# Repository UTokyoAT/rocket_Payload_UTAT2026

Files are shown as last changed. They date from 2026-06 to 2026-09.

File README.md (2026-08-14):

# rocket_Payload_UTAT2026

輸送機班2026年度の新人研修期間中の上級生での活動。CanSatを搭載したペットボトルロケットを開発するためのリポジトリ

---

## ドキュメント

- [環境構築](docs/setup.md)
- [書き込み方法](docs/flashing.md)
- [制御構造・アーキテクチャ](docs/architecture.md)
- [地上局セットアップ](docs/ground-station.md)
- [JLCPCB 発注手順](docs/pcb-ordering.md)

---

## ディレクトリ構造

XIAO ESP32S3を2枚（XIAO1・XIAO2）使い、SPIで接続する構成。詳細は [architecture.md](docs/architecture.md) を参照。

```
rocket_Payload_UTAT2026/
│
├── platformio.ini           # ビルド・ボード・ライブラリ設定（env:xiao1 / env:xiao2 他）
│
├── include/
│   ├── shared.h             # XIAO1タスク間共有データ（SensorData・MissionState）
│   └── spi_protocol.h       # XIAO1⇔XIAO2間のSPIフレーム定義（SpiFrameToXiao2 他）
│
├── src/
│   ├── xiao1/                       # センサー・GPS・誘導PID計算（SPIマスター）
│   │   ├── main.cpp                 # 起動・タスク生成
│   │   └── tasks/
│   │       ├── task_sensor.h        # IMU・気圧・地磁気読み取り＋姿勢フィルタ（100Hz, Core1）
│   │       ├── task_gps.h           # GPS受信・パース（Core0）
│   │       ├── task_navigation.h    # 誘導PID計算（100Hz, Core1）
│   │       ├── task_mission.h       # ミッションステート遷移（20Hz, Core1）
│   │       └── task_spi_link.h      # XIAO2への送信（100Hz, Core1）
│   └── xiao2/                       # モータ駆動・WiFiテレメトリ中継（SPIスレーブ）
│       └── main.cpp
│
├── lib/
│   ├── Sensor/              # BMP280・MPU6050・BMM350 ドライバ＋姿勢フィルタ  ─ XIAO1
│   ├── GPS/                 # TinyGPSPlus ラッパー                          ─ XIAO1
│   ├── PID/                 # 汎用PIDコントローラ                          ─ XIAO1
│   ├── SpiLinkMaster/       # XIAO2へのSPI送信（マスター側）                ─ XIAO1
│   ├── SpiLinkSlave/        # XIAO1からのSPI受信（スレーブ側）              ─ XIAO2
│   ├── Radio/               # WiFi SoftAP・HTTP GETでバイナリフレーム配信（PULL方式） ─ XIAO2
│   ├── Actuator/            # モーター制御（TB6612FNG）                     ─ XIAO2
│   └── Deployer/            # ロケット分離・パラシュート分離（ニクロム線）・LED ─ XIAO1
│
├── ground/
│   ├── receiver.py          # HTTP GETポーリング受信＋CSVロギング＋Tkinter GUI
│   ├── mock_device.py       # 実機なしでreceiver.pyを確認するためのモック
│   ├── requirements.txt
│   └── logs/                # 保存されたCSVログ（.gitignore推奨）
│
├── hardware/
│   ├── kicad/               # KiCad プロジェクトファイル
│   └── jlcpcb/
│       ├── gerbers/         # Gerberファイル（発注用ZIP）
│       ├── bom/             # Bill of Materials
│       └── cpl/             # Component Placement List
│
└── docs/                    # ドキュメント
```

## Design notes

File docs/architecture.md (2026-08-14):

# 制御構造・アーキテクチャ

## 概要

XIAO ESP32S3を **2個** 使用し、SPIで接続する。GPIOがXIAO ESP32S3 1枚では足りない（センサーI2C×3・GPS UART・ニクロム線×2・モーター用SPIをすべて1枚に収められない）ため、役割ごとに基板を分けた。

```
             SPI（XIAO1がマスター）
XIAO1 ─────────────────────────────► XIAO2
（センサー・GNSS・誘導PID）      （モーター駆動・WiFiテレメトリ中継）
```

| | XIAO1（マスター） | XIAO2（スレーブ） |
|---|---|---|
| 役割 | センサー読み取り・GPS・誘導フュージョン・PID計算・ミッションステート管理・ニクロム線分離機構 | モーター駆動・WiFi通信（テレメトリ配信・手動操作受信） |
| 実装方式 | デュアルコア＋FreeRTOSタスク（`loop()`は使わない） | シンプルな`setup()`/`loop()` |
| 主なlib | Sensor, GPS, PID, Deployer, SpiLinkMaster | Radio, Actuator, SpiLinkSlave |
| PlatformIO env | `xiao1` | `xiao2` |

XIAO1が姿勢・GPS・誘導PID出力まで計算しきってSPIでXIAO2へ送り、XIAO2はそれをそのままモータへ反映しつつ、同じフレームをWiFiで地上局へ中継する（地上局からの手動操作コマンドもXIAO2が直接WiFiで受信し、SPI経由の中継はしない）。

SPI通信の詳細（フレームフォーマット・ピン）は末尾の「[XIAO1 ⇔ XIAO2 通信（SPI）](#xiao1--xiao2-通信spi)」を参照。

---

## XIAO1 タスク構成

```
Core 0                            Core 1（リアルタイム系）
────────                          ──────────────────────────────────
taskGPS  priority 3               taskSensor      priority 5  ← 100Hz 最優先
                                   taskNavigation  priority 4  ← 誘導PID計算
                                   taskMission     priority 4  ← ミッションステート遷移
                                   taskSpiLink     priority 3  ← XIAO2への送信
```

Core 1の4タスクはセンサー→誘導PID・ミッション判定→SPI送信の依存順に優先度を割り当てている。

| タスク | 周期 | 役割 |
|---|---|---|
| taskSensor | 100Hz | IMU・気圧・地磁気を読み、姿勢フィルタ（重力ベクトルの相補フィルタ＋地磁気チルト補正）を回す。BMM350のODRも100Hzに設定（`lib/Sensor`） |
| taskNavigation | 100Hz | GPS方位とyawの誤差（磁気偏角補正込み）をPIDで補正し、旋回量(`pidOutput`)と目的地方位(`destinationYaw`)をSharedへ書き込む。GPS fix未取得中は出力0固定 |
| taskMission | 100Hz（10ms） | SETTING〜GOAL/ABORTEDのシーケンスを進行させ`Shared.state`を更新し、`lib/Deployer`（ニクロム線・LED）を制御する。詳細は「[ミッションステート遷移](#ミッションステート遷移)」参照 |
| taskSpiLink | 100Hz | センサー値・誘導PID出力・ミッションステートをXIAO2へ送信し、応答フレーム（地上局が設定した目的地）を受け取る |
| taskGPS | イベント駆動 | NMEAをバイト単位でパース。fix有無・衛星数・新規fix到着を`gpsValid`/`gpsSatellites`/`gpsFixSeq`としてSharedへ書き込む |

---

## タスク間データ共有（XIAO1内）

XIAO1内の全タスクが `Shared` 構造体 1つを参照する。mutex で排他制御。XIAO2とはこの構造体を共有しておらず、taskSpiLinkがSPI経由で値をやり取りする。

```
include/shared.h
┌────────────────────────────────────────────────────┐
│ struct SensorData {                                │
│   float alt, roll, pitch, yaw;                     │
│   double lat, lon;                                 │
│   uint32_t timestamp_ms;                           │
│   bool gpsValid;                                   │
│   int gpsSatellites;      ← taskGPSが計算          │
│   uint32_t gpsFixSeq;     ← taskGPSが計算          │
│   float pidOutput;        ← taskNavigationが計算   │
│   float destinationYaw;   ← taskNavigationが計算   │
│ };                                                  │
│ struct Shared {                                    │
│   SemaphoreHandle_t mutex;                         │
│   SensorData latest;                               │
│   MissionState state;    ← taskMissionが更新       │
│   double goalLat, goalLon; ← taskMission/taskSpiLinkが更新 │
│ };                                                  │
└────────────────────────────────────────────────────┘
```

- **書き込み**: taskSensor（alt/roll/pitch/yaw/timestamp_ms）、taskGPS（lat/lon/gpsValid/gpsSatellites/gpsFixSeq）、taskNavigation（pidOutput/destinationYaw）、taskMission（state/goalLat/goalLon）、taskSpiLink（goalLat/goalLon、地上局が`GET /goal`を送った場合のみ）
- **読み取り**: taskNavigation（yaw/lat/lon/gpsValid/goalLat/goalLon）、taskMission（alt/roll/pitch/gpsValid/gpsSatellites/lat/lon/gpsFixSeq）、taskSpiLink（XIAO2への送信用）

---

## ライブラリ構成（lib/）

タスク／`loop()`はlibの薄いラッパーとして機能し、ロジックはすべてlib側に閉じ込める。

```
src/xiao1/tasks/task_xxx.h                    src/xiao2/main.cpp
    │  lib を呼ぶだけ                              │  lib を呼ぶだけ
    ▼                                              ▼
lib/Sensor/          BMP280（気圧）・MPU6050（6軸）・BMM350（地磁気）ドライバ＋姿勢フィルタ   ─ XIAO1
lib/GPS/             TinyGPSPlus をラップしたGPS読み取りクラス（GY-GPSV2-NEO6M）＋方位・距離計算 ─ XIAO1
lib/PID/             汎用PIDコントローラ                                                  ─ XIAO1
lib/SpiLinkMaster/   XIAO2への送信＋応答受信（全二重SPI、標準SPIライブラリを使用）           ─ XIAO1
lib/SpiLinkSlave/    XIAO1からのトランザクション受信（hideakitai/ESP32SPISlaveを使用）      ─ XIAO2
lib/Radio/           WiFi SoftAP 立ち上げ・HTTP GET でバイナリフレーム配信（PULL方式）        ─ XIAO2
lib/Actuator/        モーター（TB6612FNG、3ピン/モーター＋共有STBY方式で左右独立駆動）         ─ XIAO2
lib/Deployer/        ロケット分離・パラシュート分離（いずれもニクロム線でテグス溶断）・LED     ─ XIAO1
lib/DebugLog/        WiFi SoftAP + HTTPでテキストログ配信（tests/配下の単体動作確認専用。本番では未使用）
```

ミッションステート遷移ロジック自体は`lib/`ではなく`src/xiao1/tasks/task_mission.h`に置いている（Sensor/GPS/Deployerなど複数libを横断的に読み書きする調停役のため、他タスクと同じく「libを呼ぶだけの薄いラッパー」ではなく、libをまたぐ状態管理そのものがこのタスクの本体になる）。

---

## ミッションステート遷移

`src/xiao1/tasks/task_mission.h`（`taskMission`、10ms周期）が実装する。実際の運用フローチャートに基づく7状態。「tick」はtaskMission自身の10ms周期を指す（NAVIGATEの停止判定のみ、GPSの実際の更新間隔に合わせて「新規fixの到着回数」で数える。理由は後述）。tick数（LAUNCH_CONFIRM_TICKS等）は50ms周期だった頃の値のまま据え置いているため、各確認時間は5分の1に短縮されている点に注意。

```
SETTING ──衛星10個以上を捕捉──► LAUNCH ──高度8m超を5tick連続検知──► DETACH
   │ 10分タイムアウト                                                  │ deployRocket()
   ▼                                                                    │ 高度変化1m未満を100tickごとに5回連続検知
ABORTED ◄───────────────────────────────────────────────────────────────┤
   ▲                                                                    ▼
   │ 5分タイムアウト                                                 UNFOLD
   │（安定したが20度以内に収まらない）                                  │ deployParachute()
   └──────────────────────────────────────────────────────────────────┤ 変化幅10度以下(直近10tick)
                                                                        │ かつ絶対値20度以下を5tick連続検知
                                                                        ▼
   ABORTED ◄── 10分タイムアウト（停止を検知できず） ──────────── NAVIGATE
      │                                                                 │ 緯度・経度どちらも変化が0.00001度以下を
      │                                                                 │ 新規fixで1回検知→以後5回連続で再確認
      ▼                                                                 ▼
  LED点滅で異常を通知し続ける                                          GOAL ── LED点滅（回収支援）
  （モータはNAVIGATE以外では動かないため自然に停止する）
```

各遷移のトリガーとしきい値（すべて`task_mission.h`冒頭の定数）：

| 遷移 | トリガー |
|---|---|
| SETTING → LAUNCH | GPS衛星捕捉数が`SETTING_MIN_SATELLITES`（10個）以上、かつfix取得済み。このとき現在のGPS座標を`Shared::goalLat/goalLon`（＝打ち上げ地点）として記録する |
| SETTING → ABORTED | `SETTING_TIMEOUT_MS`（10分）経過しても衛星10個に届かない |
| LAUNCH → DETACH | 高度が`LAUNCH_ALT_THRESHOLD_M`（8m）を`LAUNCH_CONFIRM_TICKS`（5tick=0.05秒）連続で超える。タイムアウトなし（発射操作を待ち続ける） |
| DETACH → UNFOLD | 遷移時に`Deployer::deployRocket()`（ロケットから分離）。以後、`DETACH_ALT_SAMPLE_TICKS`（100tick=1秒）ごとにサンプリングした高度変化が`DETACH_ALT_DELTA_THRESHOLD_M`（1m）未満を`DETACH_CONFIRM_TICKS`（5回連続＝計5秒相当）検知＝着地。タイムアウトなし |
| UNFOLD → NAVIGATE | 遷移時に`Deployer::deployParachute()`（パラシュート分離）。直近`UNFOLD_STABLE_WINDOW_TICKS`（10tick=0.1秒）のroll/pitch変化幅がともに`UNFOLD_STABLE_RANGE_DEG`（10度）以下、かつ`abs(roll)`/`abs(pitch)`がともに`UNFOLD_UPRIGHT_ABS_DEG`（20度）以下を`UNFOLD_UPRIGHT_CONFIRM_TICKS`（5tick=0.05秒）連続で検知 |
| UNFOLD → ABORTED | `UNFOLD_TIMEOUT_MS`（5分）経過しても上記条件を満たさない（変化は収まった＝安定したが20度以内に収まらない＝回収不能と判断） |
| NAVIGATE → GOAL | `Shared::goalLat/goalLon`へ向けた自律走行中、緯度・経度**どちらも**変化が新規GPS fixで`NAVIGATE_STOP_DELTA_DEG`（0.00001度）以下であることを1回でも検知したら「停止候補」とし、そこから改めて新規fix`NAVIGATE_STOP_CONFIRM_FIXES`（5回）分すべてが同条件を満たすことを再確認できたら＝停止（到達）。再確認中に1回でも超えたら候補を取り消し、次に条件を満たす新規fixが来るところから数え直す。片方だけで判定すると、進行方向が南北/東西に近いときもう片方の軸がほぼ動かず誤検知するためAND条件にしている |
| NAVIGATE → ABORTED | `NAVIGATE_TIMEOUT_MS`（10分）経過しても停止を検知できない |

**DETACHの着地判定を1tickではなく100tickごとに間引く理由**：1tick（10ms）間隔の生の高度差分は気圧センサーのノイズで振動しやすく、着地していなくても閾値未満に見えて誤検知しかねない。そのため`DETACH_ALT_SAMPLE_TICKS`（100tick=1秒）間隔で高度をサンプリングして差分を取り、そのサンプル単位で`DETACH_CONFIRM_TICKS`（5回）連続して閾値未満なら着地と判定する（着地判定にかかる時間は合計で約5秒）。

**NAVIGATEの停止判定だけ「tick」ではなく「GPS fix到着回数」で数える理由**：GPSは実際には1Hz程度でしか更新されないため、taskMissionの10ms周期でそのまま緯度経度をサンプリングすると、同じ古い値を何度も連続で読んでしまい「移動していない」と誤判定しかねない。そのため`taskGPS`が新規fix受信のたびインクリメントする`SensorData::gpsFixSeq`の変化を検知したときだけ判定する。

**NAVIGATEの停止判定が「1回検知→改めて5回再確認」の2段構えになっている理由**：最初から5回連続一致を要求すると、たまたま最初の数回だけ条件を満たさなかった場合に0からやり直しになり判定が遅れる。そこで1回でも条件を満たした時点をいったん「停止候補」として記録し、そこから独立に5回分の新規fixで再確認する。再確認の途中で1回でも条件を外れたら停止候補を取り消し、次に条件を満たす新規fixが来たところから改めて5回のカウントを始める。

**ABORTED/GOALの共通挙動**：`Deployer::beepPattern()`を呼び続けてLEDを点滅させ、回収支援の位置知らせを継続する。区別はテレメトリの`mission_state`の値で行う。モータはXIAO2側で`MissionState::NAVIGATE`のときしか自律走行しないため（後述）、ABORTED/GOALでは特別な停止処理をせずとも自然にモータが止まる。

---

## 無線通信

地上PCとはWiFi SoftAPで常時接続し、PULL方式（地上PC側がHTTP GETで定期的に取りに行く）でテレメトリを配信する。SDカードは使用しない。

機体→PCへのPUSH（WebSocketブロードキャストやPOST）は、PC側ファイアウォールに着信をブロックされる環境があり信頼できないため採用しない。地上PCからのアウトバウンドGETは許可されやすいため、PULL方式に統一している。

```
ESP32-S3（SoftAP: CanSat-AP、XIAO2が担当）
    │  GET http://192.168.4.1/data
    │  37バイト バイナリフレーム（ポーリング間隔 100〜150ms 目安）
    ▼
地上PC（ブラウザ or Pythonスクリプト）
    └─ データ記録・リアルタイム表示
```

WiFi/HTTPは**XIAO2**が担当する（XIAO1はSPI送信のみでWiFiを持たない）。XIAO1がSPIで送った`SpiFrameToXiao2`を、XIAO2がXIAO1のloop()内で`Radio::setData()`にそのまま渡し、リクエストごとに読み直して返す（`Radio::poll()` を呼ぶたびに保留中のHTTPリクエストを処理する）。ブラウザ用の簡易ダッシュボード（`GET /`）も同じ `/data` を`fetch()`でポーリングする。

地上局からのモーター手動制御は `GET /motor?left=-255〜255&right=-255〜255` で受け付ける（PCから機体へのアウトバウンド方向なので、`/data`のPULLと同じく信頼できる方向）。`Radio::getMotorCommandLeft()`/`getMotorCommandRight()` は、`MOTOR_COMMAND_TIMEOUT_MS`（1000ms）以上新しいコマンドが来ていなければ自動的に0を返すフェイルセイフを持つ。地上局側（`ground/receiver.py`）は手動制御が有効な間、250ms間隔でコマンドを送り続けることでこのタイムアウトより十分短い周期を維持する。

このコマンドはXIAO2が直接WiFiで受信し、SPI経由の中継はしない（XIAO1はWiFiを持たないため関与しない）。手動操作と自律PID（XIAO1側で計算した`pid_output`）のどちらを優先するかは、`Radio::hasRecentMotorCommand()`（タイムアウト以内に手動コマンドを受信しているか）で`src/xiao2/main.cpp`の`loop()`が判定する。フラグではなく「直近に手動コマンドが来ているか」で判定するため、`SpiFrameToXiao2`側に調停フラグは持たない。ただし自律PID出力（`else if`側）は`mission_state`が`NAVIGATE`のときしか反映されない（手動操作はステートに関わらず常に優先）。詳細は「[ミッションステート遷移](#ミッションステート遷移)」参照。

誘導PIDの目的地座標の既定値は、SETTINGシーケンス完了時に`taskMission`が取得したGPS座標（＝打ち上げ地点）で、以後NAVIGATEはこの地点へ戻る形（return-to-launch）で走行する。地上局はこれを`GET /goal?lat=..&lon=..`でいつでも上書きできる。モーターコマンドと異なりタイムアウトで無効化されない（通信が途切れたからといって目的地を失わせるのは危険なため、明示的に上書きされるまで保持する）。この座標はXIAO1側の誘導計算（`task_navigation.h`）で使うため、XIAO2が受信した値をSPIの応答フレーム（`SpiFrameFromXiao2`、XIAO2→XIAO1方向）に載せてXIAO1へ送り返す。`ground/receiver.py`は`--dest-lat`/`--dest-lon`起動引数を指定すると、地図表示用の目的地としてだけでなくこの`/goal`エンドポイントにも同じ座標を送るため、地上局の表示上の目的地と機体が実際に向かう先が食い違わない。

誘導PIDの統合動作確認は本番のXIAO1+XIAO2ペア（`env:xiao1`/`env:xiao2`をSPI接続）で行うのが基本だが、`tests/test_navigation`はXIAO1単体で誘導ロジックだけを素早く確認するための補助テストとして別途用意している。Sensor・GPSに加え、本来XIAO2側にしかないモーターをベンチ確認用に直結する（`lib/Actuator`はXIAO2の実配線＝I2C/GPSピンと衝突するため使えず、空いているD0-D3で簡易2ピン方式の仮配線にする）。`lib/Radio`を流用し、`GET /goal?lat=..&lon=..`で受け取った目的地へ、GPS fix取得済みの間だけPID走行する（fix未取得・目的地未受信の間はモーターを動かさない）。テレメトリは本番と同じ`SpiFrameToXiao2`レイアウトで`/data`から見られる。

受信バイナリフレームフォーマット（リトルエンディアン、37バイト。`include/spi_protocol.h` の`SpiFrameToXiao2`をそのまま中継しているので詳細はそちら参照）：

| Offset | Size | 型 | フィールド | 備考 |
|---|---|---|---|---|
| 0 | 4 | uint32 | timestamp_ms | 起動からのms |
| 4 | 4 | float32 | alt | 高度 [m] |
| 8 | 4 | float32 | roll | ロール角 [deg] |
| 12 | 4 | float32 | pitch | ピッチ角 [deg] |
| 16 | 4 | float32 | yaw | ヨー角 [deg] |
| 20 | 4 | float32 | lat | 緯度（doubleから縮小） |
| 24 | 4 | float32 | lon | 経度（doubleから縮小） |
| 28 | 1 | uint8 | mission_state | `MissionState`のenum値 |
| 29 | 4 | float32 | pid_output | 誘導PIDの旋回量（-255〜255） |
| 33 | 4 | float32 | destination_yaw | 目的地への方位角 [deg]（磁北基準） |

---

## XIAO1 ⇔ XIAO2 通信（SPI）

XIAO1がマスター、XIAO2がスレーブ。全二重トランザクション1回で双方向のデータを同時にやり取りする。

```
XIAO1（マスター）                              XIAO2（スレーブ）
  taskSpiLink（100Hz）                           loop()
      │  SpiLinkMaster::transfer(out) ──────────►│ SpiLinkSlave::poll(in)
      │  ＝ SPI.transferBytes()（全二重）          │ ＝ ESP32SPISlaveのqueue/trigger方式
      │◄────────────────────────────────────────│ SpiLinkSlave::setResponse(out)
      ▼                                              │
  Shared::goalLat/goalLonを更新                        ├─ モータへ反映（pid_output or 手動コマンド）
  （goal_valid=1のときのみ）                            └─ Radio::setData()でWiFiテレメトリに反映
```

契約は `include/spi_protocol.h` にある。変更する場合は `lib/SpiLinkMaster` と `lib/SpiLinkSlave` 両方への影響を確認すること。

**XIAO1 → XIAO2（`SpiFrameToXiao2`）**

| フィールド | 型 | 備考 |
|---|---|---|
| timestamp_ms | uint32 | 起動からのms |
| alt / roll / pitch / yaw | float32 | XIAO1のSensorでフュージョン済みの姿勢・高度 |
| lat / lon | float32 | GPS座標（doubleから縮小） |
| mission_state | uint8 | `MissionState`のenum値 |
| pid_output | float32 | `task_navigation.h`が計算した誘導PIDの旋回量（-255〜255） |
| destination_yaw | float32 | `task_navigation.h`が計算した目的地への方位角 [deg]（磁北基準） |

XIAO2はこのフレームをそのままWiFiテレメトリとしても中継する（`lib/Radio`参照）。

**XIAO2 → XIAO1（`SpiFrameFromXiao2`）**

| フィールド | 型 | 備考 |
|---|---|---|
| goal_valid | uint8 | 地上局が`GET /goal`を一度でも送っていれば1。0の間は`goal_lat/goal_lon`は不定値でXIAO1側は無視する |
| goal_lat / goal_lon | float32 | 地上局が`GET /goal?lat=..&lon=..`で設定した目的地座標 |

`taskSpiLink`が`goal_valid`を見て、真の場合のみ`Shared::goalLat/goalLon`を上書きする（未設定の間は`shared.h`の既定値のまま）。

### XIAO2側の処理（モータ駆動・WiFi中継）

`src/xiao2/main.cpp` の `loop()` が、受信した`pid_output`を`BASE_SPEED ± pid_output`の左右差動出力に変換する（誘導・PID自体はXIAO1側の`task_navigation.h`で計算済み）。ただしこの自律PID出力は`mission_state`が`MissionState::NAVIGATE`のときしか反映しない（発射・分離・パラシュート展開の最中にモータが勝手に動き出さないための安全ゲート）。`Radio::hasRecentMotorCommand()`が真なら、ミッションステートに関わらず地上局からの手動コマンドを優先する。さらにXIAO1からのSPIフレームが`SPI_LINK_TIMEOUT_MS`（5秒）以上途絶えた場合は、XIAO1側の異常とみなし手動コマンドより優先してモータを強制停止する（`lastSpiFrameMs`で最終受信時刻を追跡）。優先順位は「SPI断 > 手動コマンド > NAVIGATE時の自律PID > それ以外は停止」。現状のTODO：

- `BASE_SPEED`のミッションステート依存化（現状は固定値150）

### SPIピン・ビルド上の注意

- ピン番号は `include/spi_protocol.h` の `SpiPins` 名前空間で定義。SCK/MISO/MOSIはXIAO1・XIAO2共通（D8/D9/D10）だが、CSはXIAO1側`CS_MASTER`（D0）とXIAO2側`CS_SLAVE`（D7）で異なるGPIOに配線されているため分けて定義している。
- XIAO2は `hideakitai/ESP32SPISlave` ライブラリに依存する（`platformio.ini` の `env:xiao2` にのみ追加）。マスター用（`lib/SpiLinkMaster`）とスレーブ用（`lib/SpiLinkSlave`）を別々のlibフォルダに分けているのは、PlatformIOのライブラリ依存解決がフォルダ単位でソースをコンパイルするため、同じフォルダに同居させるとXIAO1のビルドにもXIAO2専用ライブラリへの依存が混入してしまうことを避けるため。

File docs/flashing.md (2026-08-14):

# 書き込み方法

機体には XIAO ESP32S3 が **2枚** 搭載されている（[architecture.md](architecture.md) 参照）。それぞれ別のファームウェアなので、両方とも個別に書き込む必要がある。

| 基板 | 役割 | PlatformIO env |
|---|---|---|
| XIAO1 | センサー・GPS・誘導PID計算（SPIマスター） | `xiao1` |
| XIAO2 | モータ駆動・WiFiテレメトリ中継（SPIスレーブ） | `xiao2` |

---

## 1. ボードをPCに接続

USB-Cケーブルで **書き込みたい方の** XIAO ESP32S3 を接続する（2枚同時にPCへ挿してもよいが、書き込み対象を間違えないようCOMポートを確認すること）。

デバイスマネージャー（またはターミナル）でCOMポートが認識されているか確認する。

```powershell
# Windows PowerShell で確認
[System.IO.Ports.SerialPort]::GetPortNames()
```

---

## 2. ビルドして書き込む

**VS Code の PlatformIO サイドバー（アリのアイコン）から操作する：**

```
PlatformIO サイドバー → PROJECT TASKS → xiao1（またはxiao2）
  ├─ Build       ← コンパイルのみ
  ├─ Upload      ← ビルド＋書き込み
  └─ Monitor     ← シリアルモニタ（115200 baud）
```

XIAO1用のファームウェアを書き込むときは `xiao1`、XIAO2用（モーター側）を書き込むときは `xiao2` を選ぶこと。VS Code右下のステータスバーで現在選択中の環境が確認できる。

**ショートカット（現在選択中の環境に対して実行される）：**

| 操作 | ショートカット |
|---|---|
| ビルド | `Ctrl+Alt+B` |
| 書き込み | `Ctrl+Alt+U` |
| シリアルモニタ | `Ctrl+Alt+S` |

XIAO2の初回ビルド時は `hideakitai/ESP32SPISlave` ライブラリが自動でダウンロードされる（ネット接続が必要）。

---

## 3. 書き込みに失敗する場合

XIAO ESP32S3 はネイティブUSBの自動リセットで通常は書き込みモードに入るが、失敗する場合は基板上の **BOOTボタン（Bと刻印）を押しながらUSBケーブルを挿す**（またはUploadを開始してから数秒BOOTを押し続ける）と強制的に書き込みモードになる。

```
Upload開始のログが出た直後に BOOTボタンを押す → 離す
```

`platformio.ini` の該当envでポートを固定したい場合：

```ini
[env:xiao1]
extends = common
build_src_filter = -<*> +<../src/xiao1/>
upload_port = COM3   ; 自分の環境のCOMポートに変更
monitor_port = COM3
```

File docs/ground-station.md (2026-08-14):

# 地上局セットアップ

## 構成

テレメトリはPULL方式: 地上PC側（ブラウザ／Pythonスクリプト）が機体の `GET /data` を定期的にポーリングしにいく。機体からPCへ能動的にデータを送りつけることはしない（PC側ファイアウォールに阻まれ信頼できないため）。

モーター手動制御はその逆方向（PC→機体のアウトバウンド `GET /motor?left=N&right=M`）で、こちらは`/data`のPULLと同じくPC側から能動的に接続するので信頼できる。左右独立に指定し、機体側は1秒間コマンドを受信しないと自動的に両方の出力を0にするフェイルセイフを持つ。ただし自律PID走行はミッションステートが`NAVIGATE`のときしか反映されない（`src/xiao2/main.cpp`参照）ため、手動操作もその他の状態では実質的にモータを直接動かすだけになる。

誘導PIDの目的地座標も同じ方向（`GET /goal?lat=..&lon=..`）で設定できる。モーターコマンドと異なりタイムアウトでは無効化されず、明示的に上書きされるまで保持される。既定ではSETTINGシーケンス完了時に機体が取得したGPS座標（打ち上げ地点）が目的地になるが、`/goal`を送ればいつでも優先的に上書きできる。

```
ESP32-S3（CanSat）                  地上PC
──────────────────                 ─────────────────────────────────────
WiFi SoftAP                        1. CanSat-AP に接続
  SSID: CanSat-AP   ←── 接続 ──
  IP:   192.168.4.1

GET /       ──── HTML ──────────► 2. ブラウザで 192.168.4.1 を開く
GET /data   ──── 37byte frame ──► 3. ダッシュボードが150ms間隔でポーリング表示
GET /data   ──── 37byte frame ──► 4. receiver.py が100〜150ms間隔でポーリングし CSV に保存
GET /motor?left=N&right=M ◄── ok ─ 5. receiver.py の左右手動制御スライダーが250ms間隔で送信
GET /goal?lat=..&lon=..   ◄── ok ─ 6. receiver.py が --dest-lat/--dest-lon 指定時に起動時1回送信
```

---

## 単体動作確認テスト（tests/）のデバッグ出力

`tests/` 配下の各動作確認コード（`test_bmm350`・`test_bmp280`・`test_gps`・`test_i2c_scan`・`test_motor`・`test_mpu6050`）は、USBシリアルではなく **WiFi経由** でログを出す（`lib/DebugLog`）。卓上でUSBケーブルを挿さなくても、PCやスマホから確認できる。

1. PCのWiFiを **CanSat-AP** に接続（パスワード: `cansat2026`）
2. ブラウザで `http://192.168.4.1` を開く（300ms間隔で自動更新される簡易ログビューア）
   - または `GET http://192.168.4.1/log` をポーリングすればプレーンテキストで直近60行が取れる（`curl`や自作スクリプトから見る場合はこちら）

本番ファームウェア（XIAO2の`lib/Radio`）と同じSSID/パスワードを使っているため、複数の基板・テストを同時にAPとして起動しないこと（同じSSIDが衝突する。1枚ずつ書き込んで確認する運用を前提にしている）。

`Serial.begin(115200)`自体は残しているため、USBシリアルを接続していれば`DebugLog::printf()`の内容はそちらにも同時出力される（WiFiが使えない環境でのフォールバック）。

---

## test_navigation（XIAO1単体の誘導PID確認）

`tests/test_navigation`はXIAO1単体で誘導ロジックだけを素早く確認するためのテスト（`lib/DebugLog`ではなく`lib/Radio`を流用しており、本番の`/data`と同じフレームで見える）。

1. PCのWiFiを **CanSat-AP** に接続（パスワード: `cansat2026`）
2. `GET http://192.168.4.1/goal?lat=..&lon=..` で目的地を送る（ブラウザのアドレスバーでも`curl`でもよい）
3. ブラウザで `http://192.168.4.1` を開くか`receiver.py --host 192.168.4.1`で`pid_output`・`destination_yaw`・`yaw`・GPS座標を確認する

GPS fixを取得できていない、または目的地を一度も送っていない間はモーターが動かない（`pid_output`は0のまま）。動作確認するモーターは本番のXIAO2用配線ではなく、このテスト専用にD0-D3へ仮配線する（`tests/test_navigation/main.cpp`冒頭のコメント参照）。まずは車輪を浮かせた状態で確認すること。

---

## ブラウザダッシュボード

追加ソフト不要。ESP32-S3 から HTML を配信するため、接続後にブラウザで開くだけで使える。

1. PCの WiFi を **CanSat-AP** に接続（パスワード: `cansat2026`）
2. ブラウザで `http://192.168.4.1` を開く

表示内容：
- ミッションステート
- 高度・姿勢（Roll / Pitch / Yaw）
- GPS座標
- 誘導PID出力・目的地方位
- 高度の時系列グラフ（直近300点）

ページは`/data`を150ms間隔でGETポーリングしており、取得に失敗すると状態表示が「● unreachable」になる（自動的にポーリングを継続し、次に成功すれば「● reachable」に戻る）。目的地までの距離・方位・地図表示・モーター手動制御はブラウザ版では提供していない（Pythonレシーバー側のみ）。

---

## Python レシーバー（CSV ロギング＋GUI）

### セットアップ

```bash
cd ground
pip install -r requirements.txt   # GUIの地図描画に matplotlib を使用
```

GUI表示には Tkinter（python.org配布のWindows版インストーラに標準同梱）と matplotlib を使用する。

### 実行

```bash
python receiver.py
```

- Tkinterウィンドウが開き、以下をリアルタイム表示する：
  - ミッションステート・高度・姿勢（Roll/Pitch/Yaw）・GPS座標
  - 誘導PID出力（数値＋バーゲージ、-255〜255）・目的地方位（磁北基準）
  - 高度の時系列チャート
  - 現在地・機体の向き（矢印）・移動軌跡・東西南北を表示するマップ（matplotlib）
  - 目的地までの距離・方位（`--dest-lat`/`--dest-lon` 指定時のみ）
  - 左右独立の手動モーター制御パネル（下記参照）
- `ground/logs/log_YYYYMMDD_HHMMSS.csv` に自動保存
- ターミナルにも1行readoutを表示する
- GET取得に失敗しても落ちずに警告を出しながらポーリングを継続する
- ウィンドウを閉じる、または `Ctrl+C` で停止

#### 手動モーター制御（左右独立）

「有効にする」チェックボックスをオンにすると、LEFT/RIGHT各スライダー（-255〜255）の現在値を `GET /motor?left=N&right=M` として250ms間隔で機体に送り続ける。チェックを外す・STOPボタンを押す・ウィンドウを閉じる、のいずれでも即座に両方0を送信する。

安全機構（多重化）：
1. チェックを外す/STOP/終了時に明示的に left=0, right=0 を送信
2. チェックを外すと両スライダーは無効化され、それ以上コマンドを送らなくなる
3. 機体側（`Radio::getMotorCommandLeft()`/`getMotorCommandRight()`）は1秒間新しいコマンドを受信しないと自動的に両方の出力を0にする（WiFi切断や地上局クラッシュ時のフェイルセイフ）

チェックを入れた直後は実際にモーターが動くので、卓上テスト時はモーターへの配線状態に注意すること。

目的地を指定すると、マップ上に目的地（★マーク）が表示され、現在地からの距離・方位も表示される：

```bash
python receiver.py --dest-lat 35.6820 --dest-lon 139.7670
```

目的地を指定しない場合、マップは最初に受信した位置を原点として機体の軌跡・向きのみを表示する（東西南北の向きは変わらない）。

Tkinter/matplotlibが使えない環境向けに、GUIなしのターミナル＋CSVのみのモードもある（手動モーター制御はGUI専用のためheadlessでは使えない）：

```bash
python receiver.py --headless
```

接続先IPやポーリング間隔を変えたい場合：

```bash
python receiver.py --host 192.168.4.1 --interval-ms 150
```

### CSV フォーマット

| 列 | 内容 | 単位 |
|---|---|---|
| timestamp_ms | ESP32-S3 起動からの経過時間 | ms |
| alt_m | 高度 | m |
| roll_deg | ロール角 | deg |
| pitch_deg | ピッチ角 | deg |
| yaw_deg | ヨー角 | deg |
| lat | 緯度 | deg |
| lon | 経度 | deg |
| state | ミッションステート名 | - |
| pid_output | 誘導PIDの旋回量 | -255〜255 |
| destination_yaw_deg | 目的地への方位角（機体側計算、磁北基準） | deg |
| dist_to_dest_m | 目的地までの距離（`--dest-lat`/`--dest-lon`未指定時は空欄） | m |
| bearing_to_dest_deg | 目的地への方位（同上、未指定時は空欄） | deg |

### ターミナル表示例

```
Polling http://192.168.4.1:80/data every 120ms ...
Destination: 35.682000, 139.767000
Logging to logs/log_20260101_120000.csv

[NAVIGATE    ] alt= 120.30m  R=  -3.1°  P=   1.8°  Y= 275.0°  GPS=35.68124,139.76713  PID=   0.0  DESTYAW=  34.2°  DIST=  102.4m BRG= 34.2°
```

### 実機なしでの動作確認（モックデバイス）

実機が手元になくても、`mock_device.py` を使って `receiver.py` の動作を確認できる。

```bash
# ターミナル1
python mock_device.py

# ターミナル2
python receiver.py --host 127.0.0.1 --port 8000 --dest-lat 35.6820 --dest-lon 139.7670
```

`mock_device.py` は正弦波で変化するダミーの37バイトフレームを `http://127.0.0.1:8000/data` に配信し続ける。`GET /motor?left=N&right=M` も受け付け、機体と同じ1秒フェイルセイフ付きで`pid_output`（left側の値）に折り返すため、GUIの左右スライダーを動かして手動制御パネルの動作を実機なしで確認できる。`GET /goal?lat=..&lon=..` も200 okを返すだけの受け口として用意してあり、`--dest-lat`/`--dest-lon`指定時に`receiver.py`が自動送信する`GoalSender`が無限リトライし続けないようにしている。

---

## バイナリフレームフォーマット（参考）

ESP32-S3（XIAO2）が `/data` で配信する37バイトのバイナリフレーム（リトルエンディアン）。XIAO1がSPIで送った`SpiFrameToXiao2`（`include/spi_protocol.h`）をXIAO2がそのまま中継したもので、`lib/Radio/Radio.h`・`ground/receiver.py`・`lib/Radio/dashboard.h` の3箇所で共有する契約。Python側フォーマット文字列は `"<IffffffBff"`。

| Offset | Size | 型 | フィールド | 備考 |
|---|---|---|---|---|
| 0 | 4 | uint32 | timestamp_ms | 起動からのms |
| 4 | 4 | float32 | alt | 高度 [m] |
| 8 | 4 | float32 | roll | ロール角 [deg] |
| 12 | 4 | float32 | pitch | ピッチ角 [deg] |
| 16 | 4 | float32 | yaw | ヨー角 [deg] |
| 20 | 4 | float32 | lat | 緯度（機体側でdoubleから縮小） |
| 24 | 4 | float32 | lon | 経度（機体側でdoubleから縮小） |
| 28 | 1 | uint8 | mission_state | 下表参照 |
| 29 | 4 | float32 | pid_output | 誘導PIDの旋回量（-255〜255）。地上局の手動制御（`GET /motor`）が有効な間はXIAO2がそちらを優先してモータへ反映する |
| 33 | 4 | float32 | destination_yaw | 目的地への方位角 [deg]（磁北基準、XIAO1が計算） |

`mission_state` の値と対応するステート（詳細は `docs/architecture.md` の「ミッションステート遷移」参照）：

| 値 | ステート |
|---|---|
| 0 | SETTING |
| 1 | LAUNCH |
| 2 | DETACH |
| 3 | UNFOLD |
| 4 | NAVIGATE |
| 5 | GOAL |
| 6 | ABORTED |

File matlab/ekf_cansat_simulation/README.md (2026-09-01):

# CanSat 2輪走行EKF MATLABシミュレーション

`EKF_MATLAB_simulation_requirements.md`（状態遷移・観測モデル・EKF予測/更新の数式）を
土台に、出発点から約50m先の目的地へ向かう目的地誘導シナリオを実装したもの。
`run_goal_directed_simulation.m` を実行すると、Phase0（静止）→ キャリブレーション走行
（直進のみでGNSS変位から初期方位角を推定）でEKFを初期化した後、方向転換のたびに
**その時点のEKF推定位置**（実機が実際に使える唯一の情報。真値は使わない）から見た
目的地への方位角を計算して機体を向け直し、1レグ分直進する、という誘導を目的地到達
まで繰り返す。EKFの推定誤差が誘導そのものに影響する閉ループシミュレーション。
外部Toolbox不使用（`randn`/`rng`/`polyfit`等コア関数のみ）。

## ファイル構成

| ファイル | 役割 |
|---|---|
| `config_params_goal.m` | `config_params.m` を継承し、目的地・誘導ロジックのパラメータを追加 |
| `config_params.m` | 基本パラメータを一元管理（センサノイズ・機体寸法・周期など） |
| `simulate_segment.m` | 任意の初期状態から、与えた制御入力列に沿って真値・観測値を1ステップずつ生成（実行時に長さが決まる区間を継ぎ足すため） |
| `simulate_goal_directed.m` | シナリオ本体（Phase0初期化→目的地誘導ループ）。`use_encoder`フラグでEKFのエンコーダ更新有無を切り替え可能 |
| `run_ekf_over_range.m` | EKFループ本体（予測→[エンコーダ更新]→GNSS更新）を、任意区間に対して呼べる関数にしたもの。`use_encoder=false`でエンコーダ更新を丸ごとスキップ |
| `encoder_counts_to_velocity.m` | AS5600生カウント差分→ホイール周速（ラップアラウンド処理込み） |
| `latlon_to_local.m` / `local_to_latlon.m` | 緯度経度⇔ローカル座標変換 |
| `ekf_predict.m` | EKF予測ステップ |
| `ekf_update.m` | EKF更新ステップ（エンコーダ・GNSS共通の汎用形） |
| `run_goal_directed_simulation.m` | メインスクリプト（標準版、エンコーダ+GNSS） |
| `run_goal_directed_simulation_no_encoder.m` | メインスクリプト（比較版、GNSSのみ・エンコーダ更新なし） |
| `plot_results_goal.m` | 検証プロット（軌道比較の全区間図＋先頭Nレグ切り抜き図、状態誤差と±3σ） |

**誘導ロジック**: 方向転換のたびに、EKF推定位置から見た目的地への方位角を計算し、
その方向へ機体を向けてから1レグ（`leg_duration_s`秒、時間ベース）だけ直進する。目的地到達判定
（`arrival_tolerance_m`以内）もEKF推定位置基準。

**エンコーダなし比較**: `run_goal_directed_simulation_no_encoder.m` は同じシナリオ・同じ
乱数シードのまま、EKFのエンコーダ更新ステップだけを無効化する（予測+GNSS 1Hz更新のみ）。
`run_goal_directed_simulation.m` と見比べることで、車輪エンコーダによる速度フィルタリング
の有無が推定精度・誘導の安定性にどれだけ効いているかを比較できる。

**先頭Nレグの切り抜きマップ**: `plot_results_goal.m` は全区間の軌道図に加えて、
`N_LEGS_CROP`（デフォルト5）で指定した先頭レグ分だけに絞った軌道図も表示する
（走り始めの挙動を拡大して見るため、ゴール・到達許容円はこの図には出さない）。

## 実装時に補った設計判断

- **真のIMUバイアス `b_a_true`, `b_g_true`**: EKF側の過程ノイズ `sigma_rw_a`, `sigma_rw_g`
  と同じスケールでランダムウォークさせている（`simulate_segment.m`）。EKFのバイアス
  追従性能を検証する目的。固定値にしたい場合は `config_params.m` の該当sigmaを
  実質0にすればよい。
- **GNSS疑似観測値**: 真の位置→緯度経度（センサ理想出力）→位置ドメインで正規分布
  ノイズを緯度経度に変換して付加→生の緯度経度、という往復を実装。
- **エンコーダのラップアラウンド**: AS5600の12bitレジスタ差分を[-2048,2048)カウントに
  正規化してから角度差に変換。1ステップ(dt=0.05s)内に半回転を超える場合は正しく
  デラップできない前提（デフォルトパラメータでは十分な余裕あり）。
- **方向転換フェーズの走行速度**: 「左右輪駆動を想定した一定角速度」との記述から、
  その場旋回（並進速度v=0でθのみ変化）と解釈した。
- **直進の加減速モデル**: 実機は速度切替がほぼ瞬時と想定し、最初と最後の1ステップ
  (=dt=0.05s)だけ加減速するbang-bangモデル（`simulate_segment.m`内で `v_cruise/dt` の
  スパイクとして実装）。
- **旋回角**: 固定角ではなく、「EKF推定位置から見た目的地方位 − EKF推定方位角」で
  必要な旋回角を都度算出する。旋回自体はオープンループ（算出した角度÷目標角速度の
  時間だけ回頭）で、旋回中に姿勢をフィードバック補正するモデルにはしていない。
- **真の初期方位角(`theta_true_init_deg`)**: 電源投入時に機体が実際にどちらを向いて
  いるかは、静止しているPhase0中のGNSSだけではわからない（COGは移動していないと
  出ない）ため、真値側は意図的にEKFの初期の当て推量とは異なる値（デフォルト130°）に
  してある。方位角が本当に未知であることをテストするための仕掛けであり、実測すべき
  ハードウェアパラメータではない。
- **初期方位角のキャリブレーション走行**（`simulate_goal_directed.m`のPhase0直後）:
  旋回コマンドは「目的地方位 − EKF推定方位角」という*相対*角度で計算されるため、
  θの初期推定が大きく外れているとその誤差が旋回結果にそのまま乗ってしまい、GNSS
  補正だけでは収束が遅い/安定しないことがある。そこでPhase0の後、`T_calib_straight`
  秒（デフォルト10秒＝1レグと同じ長さ）だけ旋回せずに直進し、得られた複数のGNSS fix
  を時刻に対して1次回帰（`polyfit`）した傾きからEKFの初期方位角`theta_cal`とその
  推定誤差`sigma_theta_cal`を求め、それぞれx0(4)とP0(4,4)に使う。ただし`v_cruise`が
  遅くGNSSノイズが大きい設定だと、10秒の走行距離（例: 0.3m/s×10s=3m）がGNSSノイズ
  標準偏差（例: 2.12m）と同程度になり、較正の効きが弱くなる（推定誤差が1σ=40〜50°
  程度残ることもある）。実行時にコンソールへ推定値・真値との誤差・1σを表示するので、
  改善したい場合は`T_calib_straight`を伸ばすか`v_cruise`を上げると効果が大きい
  （不確かさは走行距離のほぼ逆数的に縮む）。

## 後日実測値に差し替えるべきパラメータ

`config_params.m` 内の「後日実測値に差し替え」コメント箇所（`r`, `L`,
`sigma_theta_R/L`, `sigma_a`, `sigma_rw_a`, `sigma_g`, `sigma_rw_g`, `sigma_N`, `sigma_E`,
`P0_diag`）と `config_params_goal.m` の目的地・誘導パラメータが対象。

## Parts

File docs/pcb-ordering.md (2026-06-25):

# JLCPCB 発注手順

## 必要なファイル

| ファイル | 説明 | 出力元 |
|---|---|---|
| Gerber（ZIP） | 基板データ本体 | KiCad → Plot |
| BOM（CSV） | 部品リスト（LCSC部品番号付き） | KiCad → BOM Plugin |
| CPL（CSV） | 部品実装座標リスト | KiCad → Fabrication Outputs |

出力ファイルは `hardware/jlcpcb/` に格納する。

---

## KiCad からのファイル出力手順

### Gerber

1. PCBエディタ → `File` → `Fabrication Outputs` → `Gerbers (.gbr)`
2. 出力先を `hardware/jlcpcb/gerbers/` に設定
3. 以下のレイヤーにチェックを入れる：
   - F.Cu / B.Cu（銅箔）
   - F.Silkscreen / B.Silkscreen（シルク）
   - F.Mask / B.Mask（ソルダーマスク）
   - Edge.Cuts（外形）
4. `Plot` → 続けて `Generate Drill Files`
5. `gerbers/` フォルダをZIPに圧縮してアップロード

### BOM（PCBA発注時のみ）

1. PCBエディタ → `File` → `Fabrication Outputs` → `BOM`
2. LCSC部品番号は部品プロパティの `LCSC` フィールドに記入しておく
3. 出力を `hardware/jlcpcb/bom/bom.csv` に保存

### CPL（PCBA発注時のみ）

1. PCBエディタ → `File` → `Fabrication Outputs` → `Component Placement (.pos)`
2. 形式: CSV、単位: mm、個別ファイル（表面・裏面）
3. 出力を `hardware/jlcpcb/cpl/` に保存

---

## JLCPCB サイトでの発注

1. [jlcpcb.com](https://jlcpcb.com/) にアクセス
2. `Order Now` → Gerber ZIPをアップロード
3. 基板仕様を設定（枚数・板厚・色など）
4. PCBA（実装）が必要な場合は `PCB Assembly` をONにしてBOM・CPLをアップロード
5. BOM確認画面でLCSC部品番号を照合して発注

---

## フォルダ構成

```
hardware/jlcpcb/
├── gerbers/    # Gerberファイル（ZIP化してアップロード）
├── bom/        # Bill of Materials（部品リスト）
└── cpl/        # Component Placement List（実装座標）
```

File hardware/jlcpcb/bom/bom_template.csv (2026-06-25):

Comment | Designator | Footprint | LCSC
100nF 10V | C1 | C_0402 | C1525
10kΩ | R1 | R_0402 | C25744

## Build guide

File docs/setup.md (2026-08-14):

# 環境構築

## 使用マイコン

**Seeed Studio XIAO ESP32S3**（ESP32-S3、8MB Flash / 8MB PSRAM）を **2枚** 使用し、SPIで接続する（GPIO数の都合上、センサー・GPS・誘導PID計算担当のXIAO1と、モータ駆動・WiFiテレメトリ担当のXIAO2に役割を分けている）。詳細は [architecture.md](architecture.md) を参照。

---

## 1. 必要なソフトウェアのインストール

| ソフトウェア | 説明 |
|---|---|
| [VS Code](https://code.visualstudio.com/) | エディタ |
| [PlatformIO IDE（VS Code拡張）](https://platformio.org/install/ide?install=vscode) | ESP32への書き込み・ビルド環境 |

> PlatformIO IDE をインストールすると、必要なコンパイラ・ツールチェーンが自動でインストールされます。

---

## 2. USBドライバのインストール（Windows）

XIAO ESP32S3 は ESP32-S3 のネイティブUSB（USB CDC）でPCと直接通信するため、CP2102 / CH340 のような外付けドライバは**不要**。USB-Cケーブルで接続すればデバイスマネージャーの「ポート」欄にCOMポートとして認識される。

---

## 3. リポジトリのクローン

```bash
git clone <このリポジトリのURL>
cd rocket_Payload_UTAT2026
```

---

## 4. VS Code でプロジェクトを開く

```
VS Code → File → Open Folder → rocket_Payload_UTAT2026 フォルダを選択
```

PlatformIO が `platformio.ini` を検出し、自動でライブラリ・依存関係をダウンロードする。

---

## 5. 書き込み方法

詳細は [flashing.md](flashing.md) を参照。

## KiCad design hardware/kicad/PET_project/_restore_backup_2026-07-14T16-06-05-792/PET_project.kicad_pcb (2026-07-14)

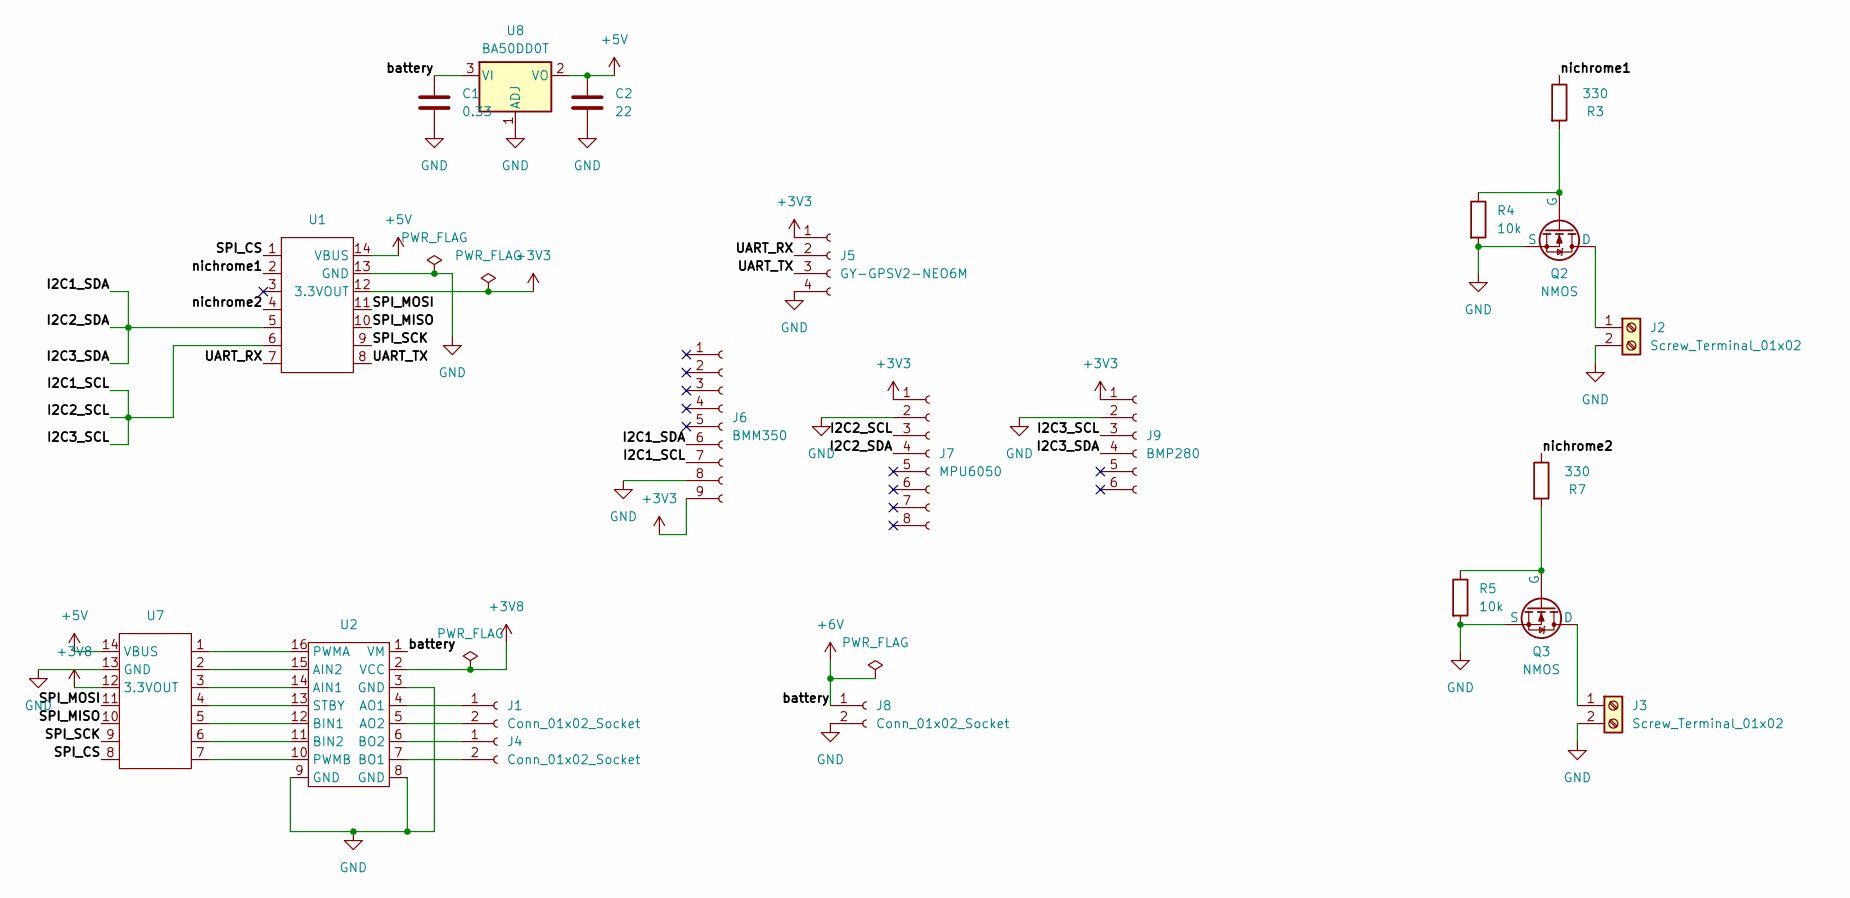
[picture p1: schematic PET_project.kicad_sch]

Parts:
C1: 0.33; CP_Radial_Tantal_D4.5mm_P5.00mm
C2: 22; C_Radial_D5.0mm_H11.0mm_P2.00mm
J1, J4: Conn_01x02_Socket; JST_XH_S2B-XH-A_1x02_P2.50mm_Horizontal
J2, J3: Screw_Terminal_01x02; TerminalBlock_Phoenix_MKDS-1,5-2-5.08_1x02_P5.08mm_Horizont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
J5: GY-GPSV2-NEO6M
J6: BMM350; BMM350_PinSocket_Vertical
J7: MPU6050; MPU6050_PinSocket_Vertical
J8: Conn_01x02_Socket; JST_PH_S2B-PH-K_1x02_P2.00mm_Horizontal
J9: BMP280; BMP280_PinSocket_Vertical
Q2, Q3: NMOS; TO-220-3_Vertical
R3, R7: 330; R_Axial_DIN0204_L3.6mm_D1.6mm_P2.54mm_Vertical
R4, R5: 10k; R_Axial_DIN0204_L3.6mm_D1.6mm_P2.54mm_Vertical
U1, U7: XIAO-ESP32-S3-DIP
U2: TB6612FNG
U8: BA50DD0T; TO-220-3_Vertical

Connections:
+3V3: J5.1, J6.9, J7.1, J9.1, U1.12 (3.3VOUT)
+3V8: U2.2 (VCC), U7.12 (3.3VOUT)
+5V: C2.1, U1.14 (VBUS), U7.14 (VBUS), U8.2 (VO)
+6V: C1.1, J8.1, U2.1 (VM), U8.3 (VI); also elsewhere on the board
/I2C1_SCL: J6.7, J7.3, J9.3, U1.6
/I2C1_SDA: J6.6, J7.4, J9.4, U1.5
/SPI_CS: U1.1, U7.8
/SPI_MISO: U1.10, U7.10
/SPI_MOSI: U1.11, U7.11
/SPI_SCK: U1.9, U7.9
/UART_RX: J5.2, U1.7
/UART_TX: J5.3, U1.8
/nichrome1: R3.1, U1.2
/nichrome2: R7.1, U1.4
GND: C1.2, C2.2, J2.2, J3.2, J5.4, J6.8, J7.2, J8.2, J9.2, Q2.3 (S), Q3.3 (S), R4.2, R5.2, U1.13 (GND), U2.3 (GND), U2.8 (GND), U2.9 (GND), U7.13 (GND), U8.1 (ADJ); also elsewhere on the board
unnamed: J1.1, U2.4 (AO1)
unnamed: J1.2, U2.5 (AO2)
unnamed: J2.1, Q2.1 (D)
unnamed: J3.1, Q3.1 (D)
unnamed: J4.1, U2.6 (BO2)
unnamed: J4.2, U2.7 (BO1)
unnamed: Q2.2 (G), R3.2, R4.1
unnamed: Q3.2 (G), R5.1, R7.2
unnamed: U2.14 (AIN1), U7.3
unnamed: U2.15 (AIN2), U7.2
unnamed: U2.12 (BIN1), U7.5
unnamed: U2.11 (BIN2), U7.6
unnamed: U2.16 (PWMA), U7.1
unnamed: U2.10 (PWMB), U7.7
unnamed: U2.13 (STBY), U7.4

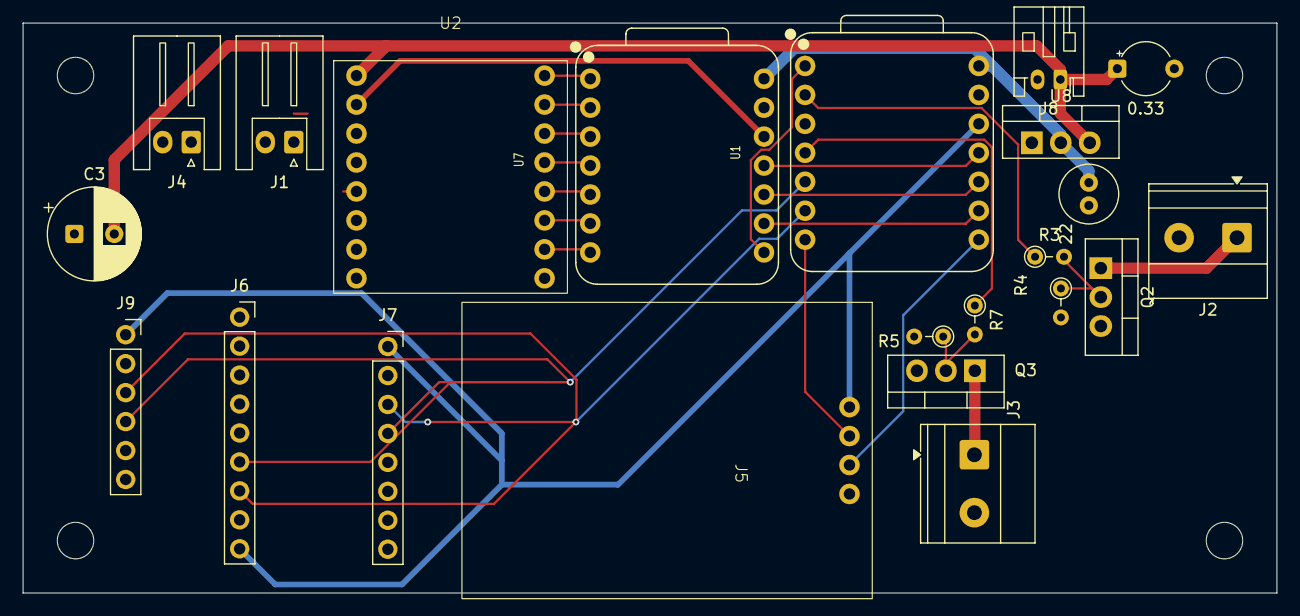
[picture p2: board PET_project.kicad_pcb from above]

Board: 2 copper layers, 110.0 x 50.0 mm, 22 parts (0 on the bottom side), 30 nets.

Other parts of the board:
C3: C; CP_Radial_D8.0mm_P3.50mm

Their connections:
+6V: C3.2; also elsewhere on the board
GND: C3.1; also elsewhere on the board

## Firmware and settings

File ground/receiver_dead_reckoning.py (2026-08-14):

"""
CanSat 地上局レシーバー（推測航法テスト専用 / Windowsネイティブ / Tkinter）

XIAO ESP32S3 の SoftAP (CanSat-AP) に接続した状態で実行する。

tests/test_dead_reckoning・test_dead_reckoning_post_detach 専用の受信スクリプト。
これらのテストファームウェアはGPSを使わないため、SpiFrameToXiao2のlat/lonフィールドを
本来のGPS度数ではなく「着地位置（原点）からのx/y距離[m]」として、yawフィールドを
真北基準ではなく「原点リセット時の機体の向きを0度とする相対ヘディング[deg]」として送ってくる
（詳細は tests/test_dead_reckoning/main.cpp の「走行軌跡の推定」コメントを参照）。

本番用の receiver.py はGPS度数（緯度経度）を前提に地図を描画するため、このテストの
データをそのまま渡すと壊れた地図になる。本スクリプトはその変換をせず、受信した
lat/lonをそのままメートル単位のローカルXY座標として描画する版。

本番のGPS目的地（--dest-lat/--dest-lon, GET /goal）機能はこのテストでは意味がないため
持たない。CSVログ・ターミナル表示・地図表示・手動モーター制御（安全停止用）は
receiver.pyと同じ構成。

使い方:
    pip install -r requirements.txt   # GUIのマップ描画に matplotlib を使用
    python receiver_dead_reckoning.py                  # GUIあり
    python receiver_dead_reckoning.py --headless        # ターミナル＋CSVのみ
"""

from __future__ import annotations

import argparse
import csv
import math
import queue
import struct
import sys
import threading
import urllib.error
import urllib.request
from collections import namedtuple
from datetime import datetime
from pathlib import Path

# ─── バイナリフレームレイアウト（機体側 include/spi_protocol.h の SpiFrameToXiao2 と共有する契約）───
# 37バイト、リトルエンディアン。フィールド構成は本番と同じだが、このテストでは
# lat/lonが「原点からのx/y距離[m]」、yawが「相対ヘディング[deg]」を表す（GPS/地磁気非使用）。
FRAME_FMT = "<IffffffBff"
FRAME_SIZE = struct.calcsize(FRAME_FMT)  # 37

Frame = namedtuple("Frame", ["t", "alt", "roll", "pitch", "heading", "x", "y", "state",
                              "pid_output", "phase_code"])

STATE_NAMES = {
    0: "SETTING",
    1: "LAUNCH",
    2: "DETACH",
    3: "UNFOLD",
    4: "NAVIGATE",
    5: "GOAL",
    6: "ABORTED",
}

# mission_state（STATE_NAMES）はXIAO2の安全ゲート用でDRIVE_STRAIGHT/DRIVE_CIRCLEどちらも
# NAVIGATE固定になり区別できないため、機体側はdestination_yawフィールドにこのテスト独自の
# 詳細フェーズ番号を載せて送ってくる（tests/test_dead_reckoning・test_dead_reckoning_post_detach
# 両方のmain.cppでこの番号に揃えてある）。
PHASE_NAMES = {
    0: "LAUNCH",
    1: "DETACH",
    2: "UNFOLD",           # post_detach版ではWAIT_ATTITUDE_SETTLE
    3: "DRIVE_STRAIGHT",
    4: "DRIVE_CIRCLE",
    5: "GOAL",              # post_detach版ではDONE
    6: "ABORTED",
}

CSV_HEADER = ["timestamp_ms", "alt_m", "roll_deg", "pitch_deg", "heading_deg",
              "x_m", "y_m", "state", "phase", "pid_output"]

# tests/test_dead_reckoning/main.cppのLAUNCH_ARM_DELAY_MS（起動からこの時間が経つまで
# 高度判定を開始しない）と同じ値。LAUNCH中の残り時間表示にだけ使う
# （post_detach版はLAUNCH状態自体が無いので単に表示されない）。
LAUNCH_ARM_DELAY_MS = 10 * 60 * 1000

LOG_DIR = Path(__file__).parent / "logs"


def format_elapsed(ms: int) -> str:
    """起動からの経過時間[ms]を H:MM:SS 形式にする。"""
    total_s = ms // 1000
    h, rem = divmod(total_s, 3600)
    m, s = divmod(rem, 60)
    return f"{h}:{m:02d}:{s:02d}"


def make_log_path() -> Path:
    LOG_DIR.mkdir(exist_ok=True)
    return LOG_DIR / f"deadreckoning_{datetime.now().strftime('%Y%m%d_%H%M%S')}.csv"


def fmt(frame: Frame) -> str:
    state_name = STATE_NAMES.get(frame.state, str(frame.state))
    phase_code = int(round(frame.phase_code))
    phase_name = PHASE_NAMES.get(phase_code, str(phase_code))
    return (
        f"\r[{state_name:<9}/{phase_name:<14}] "
        f"T+{format_elapsed(frame.t):<8} "
        f"alt={frame.alt:7.2f}m  "
        f"R={frame.roll:6.1f}°  P={frame.pitch:6.1f}°  HDG={frame.heading:6.1f}°  "
        f"pos=({frame.x:6.2f},{frame.y:6.2f})m  "
        f"PID={frame.pid_output:6.1f}"
    )


class Poller(threading.Thread):
    """バックグラウンドスレッドで /data を定期的にGETし、結果をqueueへ流す。"""

    def __init__(self, url: str, interval_s: float, timeout_s: float,
                 out_queue: "queue.Queue", stop_event: threading.Event):
        super().__init__(daemon=True)
        self.url = url
        self.interval_s = interval_s
        self.timeout_s = timeout_s
        self.out_queue = out_queue
        self.stop_event = stop_event

    def run(self) -> None:
        while not self.stop_event.is_set():
            try:
                with urllib.request.urlopen(self.url, timeout=self.timeout_s) as resp:
                    raw = resp.read()
                if len(raw) != FRAME_SIZE:
                    self.out_queue.put(("error", f"frame size mismatch: got {len(raw)}, need {FRAME_SIZE}"))
                else:
                    self.out_queue.put(("data", Frame(*struct.unpack(FRAME_FMT, raw))))
            except (urllib.error.URLError, OSError, TimeoutError) as e:
                self.out_queue.put(("error", str(e)))
            self.stop_event.wait(self.interval_s)


def _send_motor_command(url: str, left: int, right: int, timeout_s: float) -> None:
    """/motor へのベストエフォート送信（失敗しても黙って諦める）。安全停止ボタン用。"""
    try:
        urllib.request.urlopen(f"{url}?left={left}&right={right}", timeout=timeout_s)
    except (urllib.error.URLError, OSError, TimeoutError):
        pass


class MotorCommander(threading.Thread):
    """有効化されている間、現在の左右値を /motor へ定期送信し続けるバックグラウンドスレッド
    （機体はNAVIGATE中は自律走行するが、緊急停止用に手動オーバーライドできるようにしておく）。
    """

    def __init__(self, url: str, send_interval_s: float, timeout_s: float,
                 stop_event: threading.Event):
        super().__init__(daemon=True)
        self.url = url
        self.send_interval_s = send_interval_s
        self.timeout_s = timeout_s
        self.stop_event = stop_event
        self.enabled = False
        self.value_left = 0
        self.value_right = 0

    def run(self) -> None:
        while not self.stop_event.is_set():
            if self.enabled:
                _send_motor_command(self.url, self.value_left, self.value_right, self.timeout_s)
            self.stop_event.wait(self.send_interval_s)


class Recorder:
    """CSV書き込み・ターミナル表示を担当する（GUI/headless共通）。"""

    def __init__(self):
        self.log_path = make_log_path()
        self._f = open(self.log_path, "w", newline="", encoding="utf-8")
        self._writer = csv.writer(self._f)
        self._writer.writerow(CSV_HEADER)
        print(f"Logging to {self.log_path}\n")

    def on_data(self, frame: Frame) -> None:
        phase_code = int(round(frame.phase_code))
        self._writer.writerow([
            frame.t, frame.alt, frame.roll, frame.pitch, frame.heading,
            frame.x, frame.y, STATE_NAMES.get(frame.state, frame.state),
            PHASE_NAMES.get(phase_code, phase_code),
            frame.pid_output,
        ])
        self._f.flush()
        print(fmt(frame), end="", flush=True)

    def on_error(self, message: str) -> None:
        print(f"\rGET failed: {message}. retrying...", end="", flush=True)

    def close(self) -> None:
        self._f.close()


def run_headless(poller: Poller, recorder: Recorder,
                  out_queue: "queue.Queue", stop_event: threading.Event) -> None:
    poller.start()
    try:
        while True:
            kind, payload = out_queue.get()
            if kind == "data":
                recorder.on_data(payload)
            else:
                recorder.on_error(payload)
    except KeyboardInterrupt:
        print("\nStopped.")
    finally:
        stop_event.set()
        poller.join(timeout=2)
        recorder.close()


def run_gui(poller: Poller, recorder: Recorder, motor_cmd: MotorCommander,
            out_queue: "queue.Queue", stop_event: threading.Event) -> None:
    import tkinter as tk

    import matplotlib
    # matplotlibの既定フォント(DejaVu Sans)には日本語グリフが無く、軸ラベルの日本語部分が
    # 豆腐（□）化するため、Windows標準の日本語フォントを明示指定する（Tkinter側のラベルは
    # OSのフォントフォールバックで問題なく表示されるので、matplotlib側だけの対応でよい）。
    matplotlib.rcParams["font.family"] = ["Yu Gothic", "Meiryo", "MS Gothic", "sans-serif"]
    matplotlib.rcParams["axes.unicode_minus"] = False  # 上記フォントだとマイナス記号が文字化けすることがあるため

    from matplotlib.figure import Figure
    from matplotlib.backends.backend_tkagg import FigureCanvasTkAgg

    MAX_PTS = 300
    MAX_TRAIL = 2000  # 直進10m+円1周ぶんを1本の軌跡で見たいので長めに持つ
    alt_buf: list[float] = []
    trail: list[tuple[float, float]] = []

    BG = "#111"
    CARD_BG = "#1e1e1e"
    ACCENT = "#4fc"
    MUTED = "#888"
    FONT = ("Consolas", 11)
    LABEL_FONT = ("Consolas", 9)

    root = tk.Tk()
    root.title("CanSat Dead-Reckoning Monitor")
    root.configure(bg=BG)
    root.geometry("1180x820")
    root.minsize(900, 640)

    status_var = tk.StringVar(value="● unreachable")
    state_var = tk.StringVar(value="--")
    phase_var = tk.StringVar(value="--")
    elapsed_var = tk.StringVar(value="--")
    launch_arm_var = tk.StringVar(value="")
    alt_var = tk.StringVar(value="--")
    rph_var = tk.StringVar(value="--")
    pos_var = tk.StringVar(value="--")
    pid_var = tk.StringVar(value="--")

    root.columnconfigure(0, weight=0)
    root.columnconfigure(1, weight=1)
    root.rowconfigure(0, weight=1)

    left = tk.Frame(root, bg=BG)
    left.grid(row=0, column=0, sticky="ns")
    right = tk.Frame(root, bg=BG)
    right.grid(row=0, column=1, sticky="nsew")
    right.rowconfigure(0, weight=1)
    right.rowconfigure(1, weight=2)
    right.columnconfigure(0, weight=3)  # マップ（広め）
    right.columnconfigure(1, weight=1)  # 手動モーター制御（右下）

    tk.Label(left, textvariable=status_var, bg=BG, fg="#f44",
             font=FONT).pack(anchor="w", padx=12, pady=(10, 4))

    def card(parent, label: str, var: tk.StringVar, value_font=("Consolas", 18, "bold")):
        frame = tk.Frame(parent, bg=CARD_BG)
        tk.Label(frame, text=label, bg=CARD_BG, fg=MUTED,
                 font=LABEL_FONT).pack(anchor="w", padx=10, pady=(8, 2))
        tk.Label(frame, textvariable=var, bg=CARD_BG, fg=ACCENT,
                 font=value_font).pack(anchor="w", padx=10, pady=(0, 8))
        frame.pack(fill="x", padx=12, pady=4)
        return frame

    card(left, "STATE（mission_state。安全ゲート用）", state_var, value_font=("Consolas", 14, "bold"))
    card(left, "PHASE（テスト詳細フェーズ）", phase_var, value_font=("Consolas", 16, "bold"))
    card(left, "起動からの経過時間 (T+)", elapsed_var, value_font=("Consolas", 16, "bold"))
    tk.Label(left, textvariable=launch_arm_var, bg=BG, fg="#fc4",
             font=LABEL_FONT, justify="left").pack(anchor="w", padx=12, pady=(0, 4))
    card(left, "ALTITUDE [m]", alt_var)
    card(left, "ROLL / PITCH / HEADING [deg]", rph_var, value_font=("Consolas", 13))
    card(left, "推測位置 (x, y) [m]", pos_var, value_font=("Consolas", 13))

    def make_motor_gauge(parent) -> tk.Canvas:
        gauge = tk.Canvas(parent, bg=BG, width=220, height=14, highlightthickness=0)
        gauge.pack(anchor="w", padx=10, pady=(0, 4))
        return gauge

    def draw_motor_gauge(gauge: tk.Canvas, speed: int):
        gauge.delete("all")
        w, h = 220, 14
        cx = w // 2
        gauge.create_line(cx, 0, cx, h, fill=MUTED)
        frac = max(-1.0, min(1.0, speed / 255.0))
        bw = frac * (w // 2 - 4)
        color = ACCENT if speed >= 0 else "#f84"
        gauge.create_rectangle(cx, 2, cx + bw, h - 2, fill=color, outline="")

    motor_card = tk.Frame(left, bg=CARD_BG)
    tk.Label(motor_card, text="PID OUTPUT (turn)", bg=CARD_BG, fg=MUTED,
             font=LABEL_FONT).pack(anchor="w", padx=10, pady=(8, 2))
    tk.Label(motor_card, textvariable=pid_var, bg=CARD_BG, fg=ACCENT,
              font=("Consolas", 14, "bold")).pack(anchor="w", padx=10)
    pid_gauge = make_motor_gauge(motor_card)
    motor_card.pack(fill="x", padx=12, pady=4)

    # ─── 手動モーター制御（緊急停止用。左右独立、画面右下に配置） ───
    manual_frame = tk.Frame(right, bg=CARD_BG)
    tk.Label(manual_frame, text="手動モーター制御（緊急停止用）", bg=CARD_BG, fg=MUTED,
             font=LABEL_FONT).pack(anchor="w", padx=10, pady=(8, 2))

    manual_enabled_var = tk.BooleanVar(value=False)
    manual_left_var = tk.IntVar(value=0)
    manual_right_var = tk.IntVar(value=0)

    def on_slider_left_change(val: str) -> None:
        motor_cmd.value_left = int(float(val))

    def on_slider_right_change(val: str) -> None:
        motor_cmd.value_right = int(float(val))

    def stop_both(send: bool = True) -> None:
        manual_left_var.set(0)
        manual_right_var.set(0)
        motor_cmd.value_left = 0
        motor_cmd.value_right = 0
        if send:
            threading.Thread(
                target=_send_motor_command,
                args=(motor_cmd.url, 0, 0, motor_cmd.timeout_s),
                daemon=True,
            ).start()

    def on_toggle_enable() -> None:
        enabled = manual_enabled_var.get()
        motor_cmd.enabled = enabled
        scale_left.configure(state=("normal" if enabled else "disabled"))
        scale_right.configure(state=("normal" if enabled else "disabled"))
        if not enabled:
            stop_both()

    tk.Checkbutton(manual_frame, text="有効にする\n（実際にモーターが動きます）",
                   variable=manual_enabled_var, command=on_toggle_enable,
                   bg=CARD_BG, fg="#eee", selectcolor=BG, activebackground=CARD_BG,
                   justify="left", font=LABEL_FONT).pack(anchor="w", padx=10)

    tk.Label(manual_frame, text="LEFT", bg=CARD_BG, fg=MUTED,
             font=LABEL_FONT).pack(anchor="w", padx=10, pady=(4, 0))
    scale_left = tk.Scale(manual_frame, from_=-255, to=255, orient="horizontal",
                           length=160, variable=manual_left_var, command=on_slider_left_change,
                           bg=CARD_BG, fg="#eee", troughcolor=BG, highlightthickness=0,
                           state="disabled")
    scale_left.pack(anchor="w", padx=10, fill="x")

    tk.Label(manual_frame, text="RIGHT", bg=CARD_BG, fg=MUTED,
             font=LABEL_FONT).pack(anchor="w", padx=10, pady=(4, 0))
    scale_right = tk.Scale(manual_frame, from_=-255, to=255, orient="horizontal",
                            length=160, variable=manual_right_var, command=on_slider_right_change,
                            bg=CARD_BG, fg="#eee", troughcolor=BG, highlightthickness=0,
                            state="disabled")
    scale_right.pack(anchor="w", padx=10, fill="x")

    tk.Button(manual_frame, text="STOP", command=stop_both,
              bg="#f44", fg="white", font=("Consolas", 10, "bold"),
              relief="flat").pack(anchor="w", padx=10, pady=(6, 10))

    manual_frame.grid(row=1, column=1, sticky="nsew", padx=(6, 12), pady=(6, 12))

    canvas = tk.Canvas(right, bg=BG, height=180, highlightthickness=0)
    canvas.grid(row=0, column=0, columnspan=2, sticky="nsew", padx=12, pady=(12, 6))

    def draw_chart():
        canvas.delete("all")
        w = canvas.winfo_width() or 600
        h = canvas.winfo_height() or 180
        pad = 10
        if len(alt_buf) < 2:
            return
        max_v = max(max(alt_buf), 10)
        min_v = min(min(alt_buf), 0)
        rng = (max_v - min_v) or 1
        pts = []
        for i, v in enumerate(alt_buf):
            x = (i / (MAX_PTS - 1)) * w
            y = h - pad - ((v - min_v) / rng) * (h - pad * 2)
            pts.extend([x, y])
        if len(pts) >= 4:
            canvas.create_line(*pts, fill=ACCENT, width=2)
        canvas.create_text(24, pad + 6, text=f"{max_v:.1f}m", fill=ACCENT,
                            font=LABEL_FONT, anchor="w")
        canvas.create_text(24, h - 8, text=f"{min_v:.1f}m", fill=ACCENT,
                            font=LABEL_FONT, anchor="w")

    # ─── マップ（推測位置の軌跡。原点=着地位置、機体の向きは相対ヘディング）───
    fig = Figure(figsize=(5, 5), dpi=100, facecolor=BG)
    ax = fig.add_subplot(111)
    map_canvas = FigureCanvasTkAgg(fig, master=right)
    map_canvas.get_tk_widget().grid(row=1, column=0, sticky="nsew", padx=12, pady=(6, 12))

    def draw_map(frame: Frame):
        # 機体から送られてくる生のx_m/y_m・heading_degはそのままCSVに残す一方、
        # マップ描画だけは前後が逆に見えるとの実機報告があったためY軸を反転して表示する
        # （前進＝画面上方向になるようにするための表示専用の補正。ヘディング矢印も
        # 同じ反転をかけないと矢印だけ軌跡と逆向きになるので、dyも合わせて反転する）。
        x, y = frame.x, -frame.y
        trail.append((x, y))
        if len(trail) > MAX_TRAIL:
            trail.pop(0)

        ax.clear()
        ax.set_facecolor(BG)
        for spine in ax.spines.values():
            spine.set_color(MUTED)
        ax.tick_params(colors=MUTED, labelsize=8)
        ax.grid(True, color=MUTED, alpha=0.15)

        xs = [p[0] for p in trail] + [0.0]
        ys = [p[1] for p in trail] + [0.0]
        xmin, xmax = min(xs), max(xs)
        ymin, ymax = min(ys), max(ys)
        span = max(xmax - xmin, ymax - ymin, 10.0)
        cx, cy = (xmin + xmax) / 2, (ymin + ymax) / 2
        half = span / 2 * 1.3
        ax.set_xlim(cx - half, cx + half)
        ax.set_ylim(cy - half, cy + half)
        ax.set_aspect("equal", adjustable="box")

        if len(trail) >= 2:
            ax.plot([p[0] for p in trail], [p[1] for p in trail], "-",
                     color=ACCENT, alpha=0.6, lw=1.5)

        # 原点＝着地位置
        ax.plot(0.0, 0.0, marker="*", color="#f44", markersize=14, zorder=5)
        ax.annotate("LANDING", (0.0, 0.0), color="#f44", fontsize=8,
                    xytext=(4, 4), textcoords="offset points")

        ax.plot(x, y, marker="o", color=ACCENT, markersize=9, zorder=6)
        arrow_len = span * 0.15
        heading_rad = math.radians(frame.heading)
        dx, dy = arrow_len * math.sin(heading_rad), -arrow_len * math.cos(heading_rad)
        ax.annotate("", xy=(x + dx, y + dy), xytext=(x, y),
                    arrowprops=dict(arrowstyle="-|>", color="#ff0", lw=2), zorder=7)

        ax.set_xlabel("X [m]（IMU推測・ドリフトあり）", color=MUTED, fontsize=8)
        ax.set_ylabel("Y [m]（IMU推測・ドリフトあり・表示用に符号反転）", color=MUTED, fontsize=8)
        map_canvas.draw_idle()

    def drain_queue():
        try:
            while True:
                kind, payload = out_queue.get_nowait()
                if kind == "data":
                    recorder.on_data(payload)

                    status_var.set("● reachable")
                    state_var.set(STATE_NAMES.get(payload.state, str(payload.state)))
                    phase_var.set(PHASE_NAMES.get(int(round(payload.phase_code)), str(payload.phase_code)))
                    elapsed_var.set(f"T+{format_elapsed(payload.t)}")
                    phase_code = int(round(payload.phase_code))
                    if phase_code == 0 and payload.t < LAUNCH_ARM_DELAY_MS:
                        remain_ms = LAUNCH_ARM_DELAY_MS - payload.t
                        launch_arm_var.set(f"高度判定 開始まで あと {format_elapsed(remain_ms)}")
                    else:
                        launch_arm_var.set("")
                    alt_var.set(f"{payload.alt:.1f}")
                    rph_var.set(f"R:{payload.roll:6.1f}  P:{payload.pitch:6.1f}  H:{payload.heading:6.1f}")
                    pos_var.set(f"({payload.x:.2f}, {payload.y:.2f})")
                    pid_var.set(f"{payload.pid_output:6.1f}")
                    draw_motor_gauge(pid_gauge, int(payload.pid_output))
                    alt_buf.append(payload.alt)
                    if len(alt_buf) > MAX_PTS:
                        alt_buf.pop(0)
                    draw_chart()
                    draw_map(payload)
                else:
                    recorder.on_error(payload)
                    status_var.set("● unreachable")
        except queue.Empty:
            pass
        root.after(100, drain_queue)

    def on_close():
        # 念のため終了時にもモーター停止を送っておく
        _send_motor_command(motor_cmd.url, 0, 0, motor_cmd.timeout_s)
        stop_event.set()
        poller.join(timeout=2)
        motor_cmd.join(timeout=2)
        recorder.close()
        root.destroy()

    root.protocol("WM_DELETE_WINDOW", on_close)
    root.bind("<Configure>", lambda e: draw_chart())
    poller.start()
    motor_cmd.start()
    root.after(100, drain_queue)
    root.mainloop()


def main() -> None:
    parser = argparse.ArgumentParser(description=__doc__)
    parser.add_argument("--host", default="192.168.4.1", help="機体のSoftAP IP")
    parser.add_argument("--port", type=int, default=80)
    parser.add_argument("--path", default="/data")
    parser.add_argument("--interval-ms", type=int, default=120,
                         help="GETポーリング間隔 [ms]")
    parser.add_argument("--timeout", type=float, default=0.5,
                         help="GETタイムアウト [秒]")
    parser.add_argument("--headless", action="store_true",
                         help="Tkinter/matplotlibを使わずターミナル＋CSVのみで動作する")
    args = parser.parse_args()

    url = f"http://{args.host}:{args.port}{args.path}"
    motor_url = f"http://{args.host}:{args.port}/motor"
    print(f"Polling {url} every {args.interval_ms}ms ...")
    print("注意: lat/lonはGPS度数ではなく着地位置からのx/y距離[m]として解釈します"
          "（test_dead_reckoning系ファームウェア専用）。\n")

    out_queue: "queue.Queue" = queue.Queue()
    stop_event = threading.Event()
    poller = Poller(url, args.interval_ms / 1000, args.timeout, out_queue, stop_event)
    recorder = Recorder()

    if args.headless:
        run_headless(poller, recorder, out_queue, stop_event)
        return

    # 機体のフェイルセイフ（1秒無通信で自動的に出力0）より十分短い間隔で送り続ける
    motor_cmd = MotorCommander(motor_url, send_interval_s=0.25, timeout_s=0.5, stop_event=stop_event)

    try:
        run_gui(poller, recorder, motor_cmd, out_queue, stop_event)
    except ImportError as e:
        print(f"GUI依存関係が利用できないため --headless モードで動作します（{e}）。", file=sys.stderr)
        stop_event = threading.Event()
        poller = Poller(url, args.interval_ms / 1000, args.timeout, out_queue, stop_event)
        run_headless(poller, recorder, out_queue, stop_event)


if __name__ == "__main__":
    main()

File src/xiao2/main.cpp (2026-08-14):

#include <Arduino.h>
#include <Actuator.h>
#include <Radio.h>
#include "spi_protocol.h"
#include <SpiLinkSlave.h>

static const char* AP_SSID = "CanSat-AP";
static const char* AP_PASS = "cansat2026";

static SpiLinkSlave spiLink;
static Actuator actuator;
static Radio radio;

// XIAO1から最後に受信したフレーム。新しいフレームが届かない間もこれを使い続ける
// （モータ駆動・WiFiテレメトリの両方がこれを参照する）。
static SpiFrameToXiao2 lastFrame{};

// XIAO1からSPIフレームを最後に受信した時刻。SPI_LINK_TIMEOUT_MS以上更新が無ければ
// XIAO1側の異常（クラッシュ・配線断等）とみなしフェイルセイフでモータを強制停止する。
// 手動操作（Radio）より優先する（XIAO1が生きている前提でのみ機体を動かしてよいため）。
static uint32_t lastSpiFrameMs = 0;
static const uint32_t SPI_LINK_TIMEOUT_MS = 5000;

// TODO: ミッションステートに応じて前進速度を調整
// GPS/地磁気トラブル対応のtest_dead_reckoning（推測航法テスト）が直進フェーズを
// 「最大出力」で行う前提のため255（最大）にしてある。本番のGPS誘導NAVIGATEでも
// このBASE_SPEEDをそのまま使うため、誘導精度に問題が出るようなら要調整。
static const int16_t BASE_SPEED = 255;

// XIAO1が計算した誘導PID出力（旋回量）をbase±turnの左右差動出力に変換する。
static void computeAutonomousMotor(float pidOutput, int16_t& outLeft, int16_t& outRight) {
    outLeft  = constrain(static_cast<int>(BASE_SPEED - pidOutput), -255, 255);
    outRight = constrain(static_cast<int>(BASE_SPEED + pidOutput), -255, 255);
}

void setup() {
    Serial.begin(115200);
    Serial.println("XIAO2 (motor drive / WiFi telemetry) booting...");

    actuator.begin();
    spiLink.begin();
    radio.begin(AP_SSID, AP_PASS);
}

void loop() {
    if (spiLink.poll(lastFrame)) {
        SpiFrameFromXiao2 out{};
        out.goal_valid = radio.hasGoal() ? 1 : 0;
        out.goal_lat   = radio.getGoalLat();
        out.goal_lon   = radio.getGoalLon();
        spiLink.setResponse(out);
        lastSpiFrameMs = millis();
    }

    // 自律PID走行はNAVIGATE状態のときだけ有効にする（発射・分離・展開の最中に
    // pid_outputの値でモータが勝手に動き出さないようにする安全ゲート）。
    // 地上局からの手動操作コマンドはミッションステートに関わらず常に優先する。
    MissionState missionState = static_cast<MissionState>(lastFrame.mission_state);

    int16_t left, right;
    if (millis() - lastSpiFrameMs > SPI_LINK_TIMEOUT_MS) {
        left  = 0;
        right = 0;
    } else if (radio.hasRecentMotorCommand()) {
        left  = radio.getMotorCommandLeft();
        right = radio.getMotorCommandRight();
    } else if (missionState == MissionState::NAVIGATE) {
        computeAutonomousMotor(lastFrame.pid_output, left, right);
    } else {
        left  = 0;
        right = 0;
    }

    actuator.setMotorLeft(left);
    actuator.setMotorRight(right);

    radio.setData(lastFrame);
    radio.poll();
}

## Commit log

2026-06-25 開発のセットアップ
2026-06-25 hardwareのためのセットアップ
    [bom_template.csv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]
2026-06-25 セットアップ②
2026-06-25 地上局のセットアップ
2026-06-26 テストコード
2026-07-02 大量の変更。ほぼ機能を実装した
2026-07-02 動作確認前の様々な変更
2026-07-03 地上局レイアウト変更
2026-07-06 大幅実装
2026-07-07 GPSテスト用のプログラム作成
2026-07-07 GPS動作確認
2026-07-11 MPU6050のセンサ値取得
2026-07-26 だいぶ変更
2026-07-26 docsの変更
2026-07-27 へんこう
2026-07-27 テストの整備
2026-07-27 着地判定の訂正
2026-07-28 ゴール判定を変更
2026-08-01 100hzをどうにかした
2026-08-07 8月7日修正
2026-08-07 本番前のセットアップ
2026-08-08 いろいろ変更
2026-09-01 GNSS誘導しみゅれーしょん
